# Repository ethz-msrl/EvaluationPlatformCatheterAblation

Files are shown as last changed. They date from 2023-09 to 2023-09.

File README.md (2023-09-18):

# Robotic Catheter Ablation: An Evaluation and Prototyping Platform
Welcome to the setup guide for "Robotic Catheter Ablation: An Evaluation and Prototyping Platform." In this guide, we will walk you through the steps of setting up an evaluation platform for catheter ablation. Following this guide will help you calibrate and register your camera system effectively and set up the physical platform. Let's start by gathering all the necessary requirements.

## 1. Requirements
### Software requirements
- [ROS Noetic](http://wiki.ros.org/noetic/Installation/Ubuntu)
- [usb_cam](http://wiki.ros.org/usb_cam)
- [apriltag_ros](http://wiki.ros.org/apriltag_ros)
- Matlab's [Stereo Camera Calibrator](https://www.mathworks.com/help/vision/ug/using-the-stereo-camera-calibrator-app.html)

### Further requirements
- 2x endoscopic cameras
- 1x 3D-printed [STL-Files](./stl)
- 1x Printed [Apriltag](./misc/apriltag.pdf)
- 1x Printed [Checkerboard](./misc/checkerboard.pdf)
- 1x Printed [Validation Marker](./misc/tracking_validation.pdf)
- 8x M3 bolts
- 6x M3 nuts

## 2. Stereo camera setup
### Camera placement
The two endoscopic cameras are placed in the [main part](./stl/main_part.STL) of the physical setup as follows:
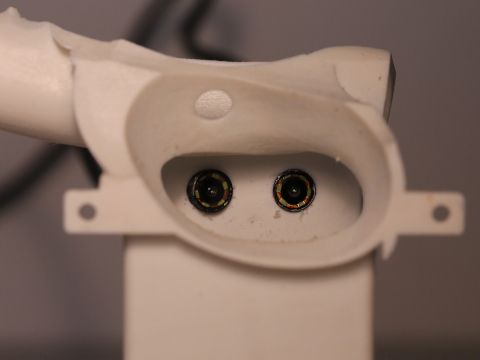
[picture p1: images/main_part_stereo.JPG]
Apriltag 1
 

_Figure 1: An illustration of the stereo camera setup showcasing the correct placement of endoscopic cameras._

Utilize M3 bolts to secure the cameras firmly in the model to prevent any movements during operation.

### Stream camera videos
To stream the videos from the two cameras, we utilize the [usb_cam](http://wiki.ros.org/usb_cam) package in ROS Noetic. The following launch file starts the two cameras and publishes the video streams to `stereo_cam_right/image_raw` and `stereo_cam_left/image_raw`:
```xml
<launch>
  <!-- Arguments -->
  <arg name="frame_rate" default="25" /> <!-- Frame rate of the video streams -->
  <arg name="pixel_format" default="yuyv" /> <!-- Pixel format of the video streams -->

  <!-- Launch right camera -->
  <node name="stereo_cam_right_node" pkg="usb_cam" type="usb_cam_node">
    <param name="camera_name" value="stereo_cam_right" />
    <param name="camera_frame_id" value="/stereo_cam_right" />
    <param name="video_device" value="/dev/<PATH_RIGHT_CAMERA>"/> <!-- Replace with the actual path to your right camera -->
    <param name="pixel_format" value="$(arg pixel_format)" />
    <param name="framerate" value="$(arg frame_rate)" /> 
  </node>

  <!-- Launch left camera -->
  <node name="stereo_cam_left_node" pkg="usb_cam" type="usb_cam_node">
    <param name="camera_name" value="stereo_cam_left" />
    <param name="camera_frame_id" value="/stereo_cam_left" />
    <param name="video_device" value="/dev/<PATH_LEFT_CAMERA>"/> <!-- Replace with the actual path to your left camera -->
    <param name="pixel_format" value="$(arg pixel_format)" />
    <param name="framerate" value="$(arg frame_rate)" /> 
  </node>
</launch>

```

Please ensure to replace <PATH_RIGHT_CAMERA> and <PATH_LEFT_CAMERA> with the appropriate paths to your right and left cameras, respectively. 

### Stereo camera calibration
Calibrating the stereo camera involves determining the intrinsic and extrinsic parameters of the individual cameras. To accomplish this, we utilize Matlab's [Stereo Camera Calibrator](https://www.mathworks.com/help/vision/ug/using-the-stereo-camera-calibrator-app.html). The [checkerboard](./misc/checkerboard.pdf) is used to calibrate the cameras by placing it at different orientations and distances with respect to the cameras. Capture multiple pairs of synchronized images of the checkerboard using both the left and right cameras. Make sure to cover various angles and distances to get a comprehensive set of data for calibration:

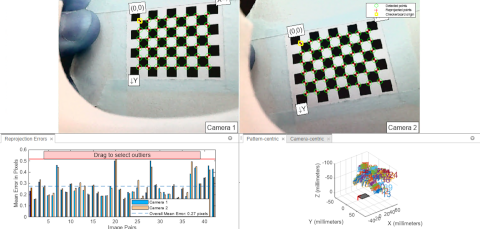
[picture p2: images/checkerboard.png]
Checkerboard


_Figure 2: An illustration of the stereo camera calibration using Matlab's Stereo Camera Calibrator._

### Apriltag registration
To obtain the transformation from the stereo camera setup to the model, we utilize aprilags, a type of fiducial marker system. Follow the steps below to set up the registration:

#### Preparation of the apriltag: 
- Print the [Apriltag marker](./misc/apriltag.pdf).
- Attach it to the registration unit as illustrated in Figure 3.
   
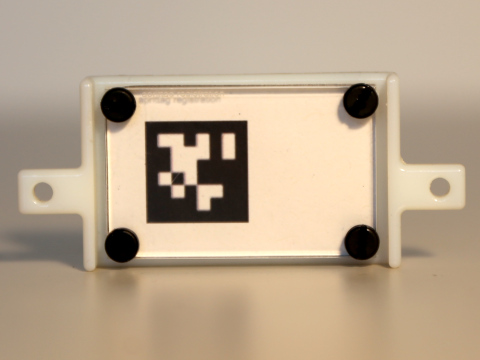
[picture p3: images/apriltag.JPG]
Apriltag

   
_Figure 3: AprilTag attached to the registration unit._

#### Attaching the registration unit: 
- Attach the registration unit to the main part of the model to allow for the extraction of transformation data.

#### **Launching the apriltag detection**:
- Utilize the [apriltag_ros package](http://wiki.ros.org/apriltag_ros) for detecting the apriltags in both the left and right camera streams. Below is the launch file that initiates the apriltag detection nodes:

 ```xml
<launch>
  <!-- Arguments -->
  <arg name="camera_name_left" default="/stereo_cam_left" />
  <arg name="camera_name_right" default="/stereo_cam_right" />
  <arg name="apriltag_definition_file" default="<PATH_TO_DEFINITION>" />
  <arg name="apriltag_settings_file" default="<PATH_TO_SETTINGS>" />

  <!-- Launch apriltag detection for the right camera -->
  <group ns="$(arg camera_name_right)"> 
    <node pkg="image_proc" type="image_proc" name="image_proc" />
    <node pkg="apriltag_ros" type="apriltag_ros_continuous_node" name="apriltag_right_cam" clear_params="true" output="screen">
      <rosparam command="load" file="$(arg apriltag_settings_file)" />
      <rosparam command="load" file="$(arg apriltag_definition_file)" />
      <param name="camera_frame" type="str" value="$(arg camera_name_right)" />
    </node>
  </group>

  <!-- Launch apriltag detection for the left camera -->
  <group ns="$(arg camera_name_left)"> 
    <node pkg="image_proc" type="image_proc" name="image_proc" />
    <node pkg="apriltag_ros" type="apriltag_ros_continuous_node" name="apriltag_left_cam" clear_params="true" output="screen">
      <rosparam command="load" file="$(arg apriltag_settings_file)" />
      <rosparam command="load" file="$(arg apriltag_definition_file)" />
      <param name="camera_frame" type="str" value="$(arg camera_name_left)" />
    </node>
  </group>
</launch>
```

### Accuracy evaluation

To evaluate the accuracy of the stereo camera setup, we triangulate two color markers. We estimate the 3D coordinates of the markers and compare them to their known positions to determine the system's accuracy. The following figure illustrates how the color marker pattern is placed in the registration unit:

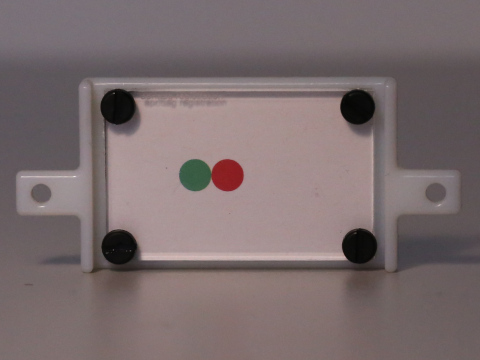
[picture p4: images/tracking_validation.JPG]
Accuracy Evaluation


_Figure 4: Evaluation color markers attached to the registration unit._

The known positions of the markers in the apriltag frame are:
  - **Green marker**: [0,0,0]
  - **Red marker**: [0.005,0,0]

## 3. GUI

In this section, we cover loading the heart model and setting up the static transformations. It is essential to correctly set up the GUI to visualize and interact with the heart model appropriately.

### Load heart model

To load the heart model, define the color and the necessary visual parameters using the following file:

```xml
<robot name="visual">
  <!-- Define color -->
  <material name="red">
    <color rgba="1 0.3 0.3 1"/>
  </material>

  <link name="pulmonary_vein_main_fixture">

    <!-- Main fixture -->
    <visual> 
      <geometry>
        <mesh filename="<PATH_TO_MAIN_PART_STL>" />
      </geometry>
      <material name="red"/>
    </visual>

    <!-- Ablation section  -->
    <visual>
      <geometry>
        <mesh filename="<PATH_TO_ABLATION_SECTION_STL>" />
      </geometry>
      <material name="red"/>
    </visual>

  </link>

</robot>
```

Next, establish the necessary launch parameters and transformations using the snippet below:

```xml
<launch>
  <!-- Load model  -->
  <arg name="model" default="<PATH_TO_URDF>"/>
  <arg name="gui" default="true"/>
  <param name="pulmonary_vein" command="$(find xacro)/xacro $(arg model)" />

  <!-- Transformation from the model to the world frame  -->
  <node pkg="tf" type="static_transform_publisher" name="pulmonary_vein_broadcaster" args="0 0 0 0 0 0 1 mns model 60" />
</launch>
```

### Static transformations

The following XML script helps in establishing the necessary static transformations from the model to the apriltag to the camera setup:

```xml
<launch>
  <!-- These nodes publish the static transformations form the apriltag -> aprilttag Mount -> model. They are know from the geometry of the calibration unit and the AprilTag -->
  <node pkg="tf" type="static_transform_publisher" name="model_to_apriltag_center_tf" args="0.0908 0.0844 0.08045 0 0 0 1 model tag_0_center 60" />
  <node pkg="tf" type="static_transform_publisher" name="apriltag_center_to_apriltag_tf" args="0 0.007 0 0.5 -0.5 -0.5 0.5 tag_0_center tag_0 60" />

  <!-- Broadcast the transformation from the apriltag to the camera frame-->
  <node pkg="tf" type="static_transform_publisher" name="apriltag_to_camera_tf" args="<PLACEHOLDER> tag_0 stereo_cam_right 60" />
</launch>
```

The model and the corresponding transformations can then be visualized in [Rviz](http://wiki.ros.org/rviz) as illustrated below:

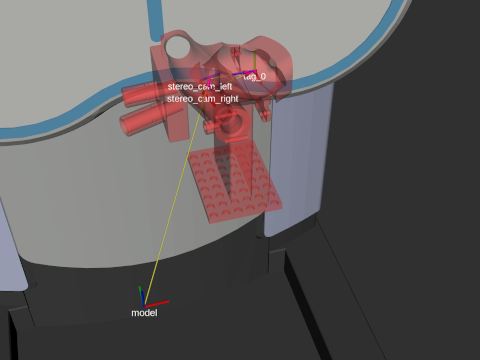
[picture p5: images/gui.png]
GUI


_Figure 6: Heart model and relevant transformations visualized in Rviz._

## 4. Physical Setup

In this section, we explain the placement of the catheter and the complete arrangement of the setup.

First, a sheath is positioned inside the model such that the opening is located in the left atrium. The following image illustrates the overall setup:

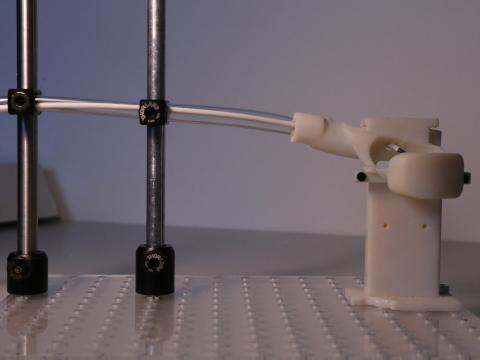
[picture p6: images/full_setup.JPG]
Full Setup


_Figure 7: The complete setup, showcasing all the components properly assembled._

The catheter is advanced through the sheath such that its color-marked tip is located inside the left atrium in front of the cameras:

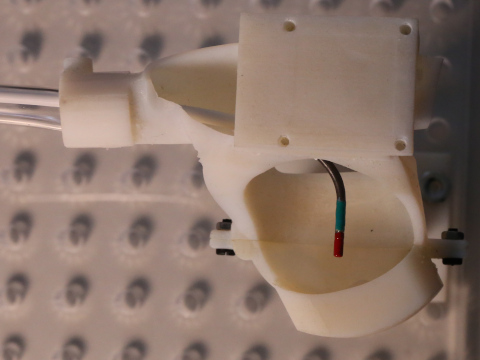
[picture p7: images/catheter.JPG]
Catheter


_Figure 8: The catheter as positioned in the physical setup._

This setup allows for the tracking of the catheter tip inside the model as illustrated in the following GIF:
Tracking GIF 

_Figure 9: A GIF demonstrating the catheter tracking system in the model._

## 5. Reference

For more detailed instructions, the reader is referred to the following publication:

```
@inproceedings{Heemeyer2023,
  doi = {10.1109/ismr57123.2023.10130271},
  url = {https://doi.org/10.1109/ismr57123.2023.10130271},
  year = {2023},
  month = apr,
  publisher = {{IEEE}},
  author = {Florian Heemeyer and Christophe Chautems and Quentin Boehler and Jos{\'{e}} L. Merino and Bradley J. Nelson},
  title = {An Evaluation Platform for Catheter Ablation Navigation},
  booktitle = {2023 International Symposium on Medical Robotics ({ISMR})}
}
```

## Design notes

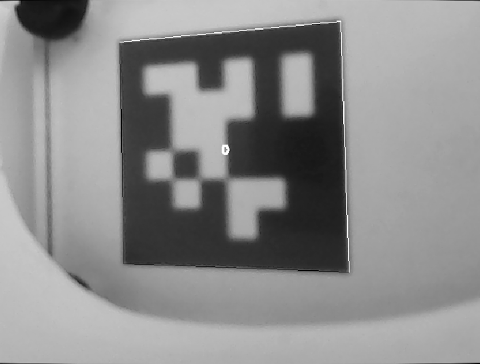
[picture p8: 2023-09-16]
images/apriltag_1.png

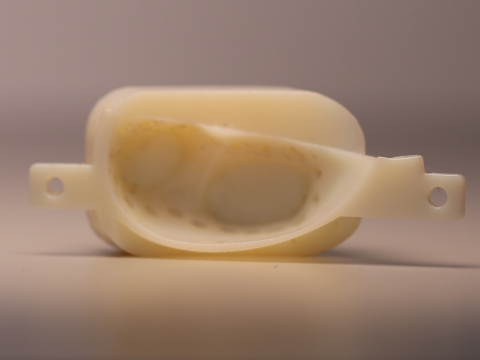
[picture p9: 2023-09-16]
images/ablation_unit.JPG

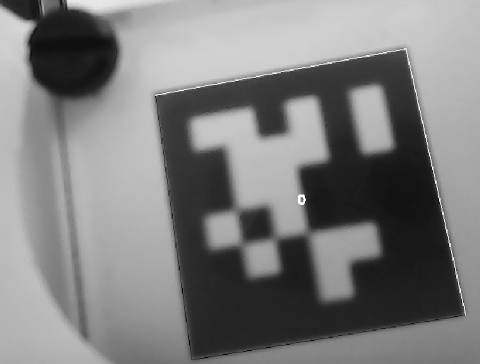
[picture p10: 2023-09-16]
images/apriltag_2.png

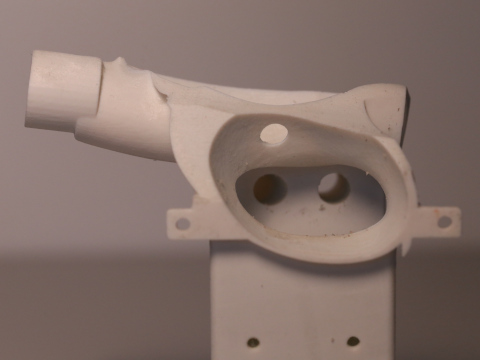
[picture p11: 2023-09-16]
images/main_part.JPG

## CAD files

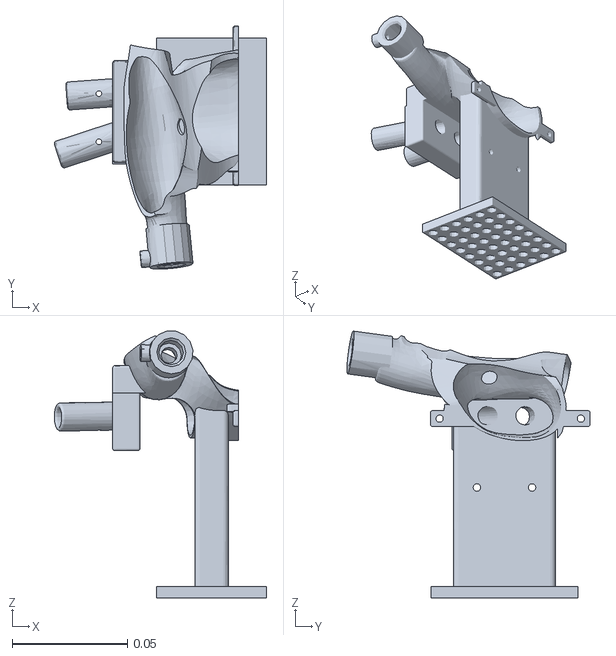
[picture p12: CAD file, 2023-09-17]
stl/main_part.STL
0.0923 x 0.106 x 0.116

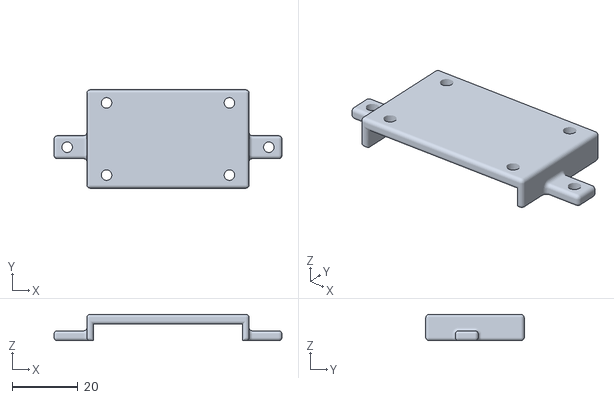
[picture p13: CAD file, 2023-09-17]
stl/registration_unit.STL
69.4 x 30.0 x 8.00

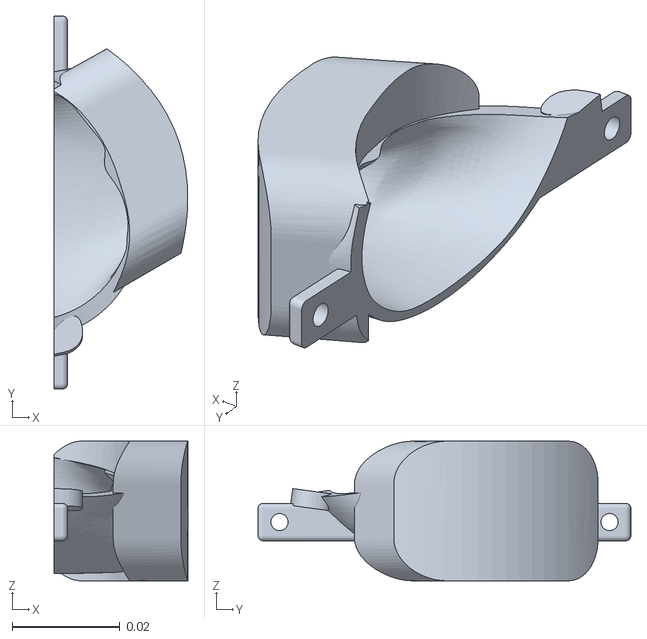
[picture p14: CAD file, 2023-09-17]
stl/ablation_section.STL
0.0248 x 0.0694 x 0.026

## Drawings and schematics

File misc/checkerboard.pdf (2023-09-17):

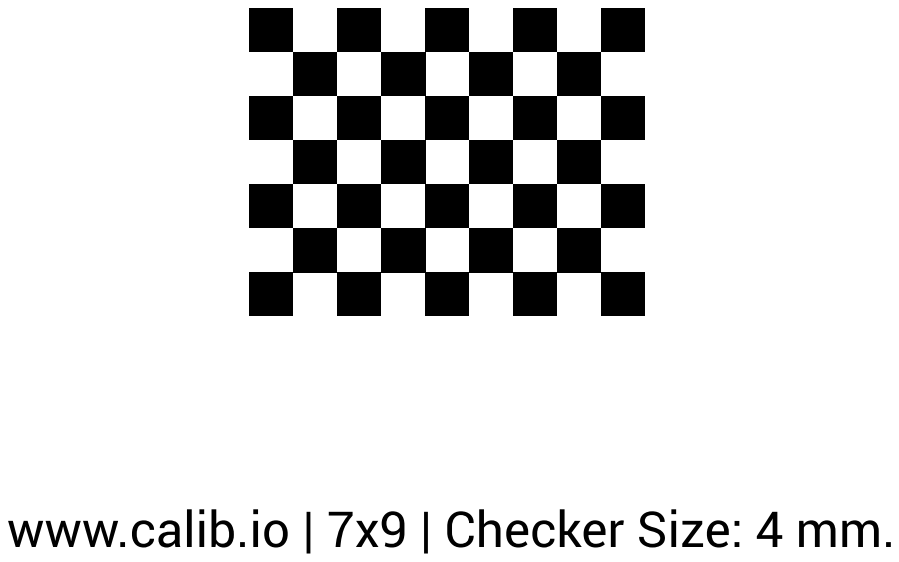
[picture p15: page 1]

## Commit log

2023-09-17 Added more images and addtional files
    [ablation_targets.csv, pulmonary_vein_contour.csv]
2023-09-17 Added stl files
    [ablation_section.STL, main_part.STL, registration_unit.STL]
